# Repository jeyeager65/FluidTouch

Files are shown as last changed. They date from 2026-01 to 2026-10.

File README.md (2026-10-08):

# FluidTouch

**A touchscreen CNC controller for FluidNC-based machines**

FluidTouch provides an intuitive 800×480 touchscreen interface for controlling CNC machines running FluidNC firmware. Built on the Elecrow CrowPanel 7" ESP32-S3 HMI display with hardware-accelerated graphics and a responsive LVGL-based UI.





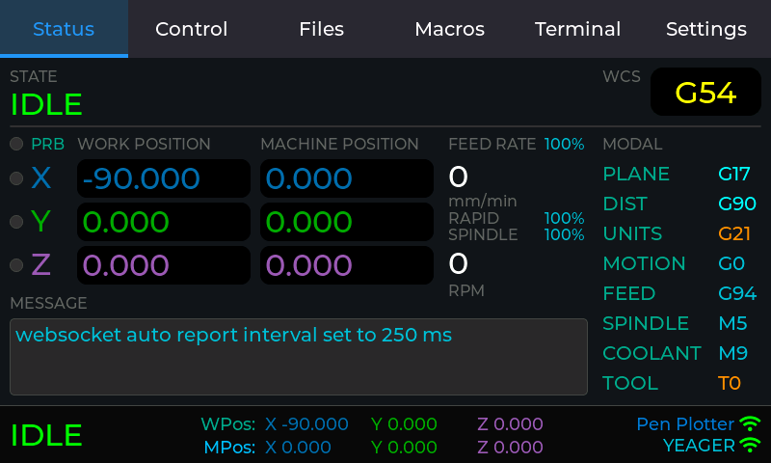
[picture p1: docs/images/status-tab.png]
FluidTouch Status


## ✨ Key Features

- **Real-time Machine Control** - Monitor position, state, feed/spindle rates with live updates from FluidNC
- **Multi-Machine Support** - Store and switch between up to 4 different CNC configurations
- **Intuitive Jogging** - Button-based and analog joystick interfaces with configurable step sizes
- **Touch Probe Operations** - Automated probing with customizable parameters for precise work coordinate setup
- **Macro Support** - Configure and store up to 9 file-based macros per machine
- **File Management** - Browse and manage files from FluidNC SD, FluidNC Flash, and Display SD card
- **Settings Backup & Restore** - Export settings to JSON, auto-import on fresh install, Clear All Settings option
- **Power Management** - Configurable display dimming, sleep, and deep sleep modes for battery operation
- **Terminal** - Execute custom commands and view FluidNC messages
- **WiFi Connectivity** - WebSocket connection to FluidNC with automatic status reporting

---

## 🚀 Quick Start

### Option 1: Web Installer (Recommended)

The easiest way to install FluidTouch is using our web-based installer:

1. **Visit:** [FluidTouch Web Installer](https://jeyeager65.github.io/FluidTouch/)
2. **Click:** "Install FluidTouch" button
3. **Connect:** Your ESP32-S3 device via USB-C
4. **Done!** Firmware flashes automatically in 30-60 seconds

**Requirements:** Chrome, Edge, or Opera browser (Web Serial API support)

### Option 2: Pre-built Binaries

Download the latest firmware from [Releases](https://github.com/jeyeager65/FluidTouch/releases) and flash using:
- [esptool.py](https://docs.espressif.com/projects/esptool/en/latest/esp32s3/index.html): `esptool.py --chip esp32s3 --port COM6 write_flash 0x10000 firmware.bin`

### Option 3: Build from Source

Refer to the **[Development Guide](./docs/development.md)** for additional instructions.

---

## 🖥️ Compatible Hardware

**Elecrow CrowPanel 7" Advance ESP32-S3 HMI Display** ⭐ *Recommended*
- ESP32-S3-WROOM-1-N16R8 (16MB Flash + 8MB PSRAM)
- 800×480 IPS RGB LCD (superior image quality)
- GT911 Capacitive Touch
- I2C Backlight Control (STC8H1K28)
- Internal battery connector (JST PH 2.0mm 2-pin)
- Optional acrylic case with battery compartment (supports ~1200mAh LiPo batteries), or a [3D printed case](./hardware/case/) with room for much larger batteries, plus a matching [table stand](./hardware/stand/)
- ⚠️ **ESP32-S3 ONLY** - ESP32-P4 versions are NOT supported
- **Hardware Versions 1.2 through 1.5 Supported**
  - **All versions:** DIP switches S0 and S1 must both be set to position 1
  - **Version 1.2:** ⚠️ Support is untested - use v1.2 firmware from web installer
  - **Versions 1.3, 1.4 and 1.5:** Fully tested and recommended. They use the same firmware: v1.4 only changed the boot/reset buttons and v1.5 only changed the silkscreen
  - **Case Note:** When using acrylic case, install 6mm M3 screws in bottom mounting inserts to prevent accidental reset button presses
- [Buy on Elecrow ↗](https://www.awin1.com/cread.php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) *(affiliate link)*

**Elecrow CrowPanel 7" Basic ESP32-S3 HMI Display**
- ESP32-S3-WROOM-1-N4R8 (4MB Flash + 8MB PSRAM)
- 800×480 TN RGB TFT LCD
- GT911 Capacitive Touch
- PWM Backlight Control
- External battery connector
- [Buy on Elecrow ↗](https://www.awin1.com/cread.php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) *(affiliate link)*

---

## 📖 Documentation

Detailed documentation is available in the [`docs/`](./docs/) folder:

- **[User Interface Guide](./docs/ui-guide.md)** - Complete UI walkthrough with screenshots
- **[Usage Instructions](./docs/usage.md)** - Operating instructions and workflows
- **[Configuration](./docs/configuration.md)** - WiFi setup, machine configuration, and settings
- **[Development Guide](./docs/development.md)** - Building, debugging, and contributing
- **[Desktop Simulator](./sim/README.md)** - Run and develop the UI on your PC, connected to a real FluidNC controller
- **[3D Printed Case](./hardware/case/README.md)** and **[Stand](./hardware/stand/README.md)** - Print files, hardware list and assembly for the Advance display

---

## 🔧 First-Time Setup

1. Power on the device
2. On the "Select Machine" screen, click the Edit button.
3. Click the "Add" button to add a new machine:
   - Name
   - Connection (currently only Wireless is supported)
   - WiFi SSID and Password (machine-specific)
   - FluidNC IP address or hostname (e.g. 192.168.0.1 or fluidnc.local)
   - WebSocket port (default: 81)
     - Port 80 is used by FluidNC v4.0+
     - Port 81 is used by WebUI v2 (FluidNC v3.x)
     - Port 82 is used by WebUI v3 (FluidNC v3.x) - only allows one connection at a time but will switch cleanly between connections
4. Click the "Save" button.
5. Click the "Done" button.
6. Click on the created machine.

---

## 🤝 Contributing

Contributions are welcome! Please read our [Development Guide](./docs/development.md) for:
- Code architecture and design patterns
- Building and testing
- Submitting pull requests

---

## 💙 Support Development

This project is provided free and open-source. Product links use affiliate codes that help offset development costs at no extra cost to you. Your support is appreciated but never required.

---

## 📝 License

This project is licensed under the MIT License - see the [LICENSE](LICENSE) file for details.

---

## 🙏 Acknowledgments

- **[FluidNC](https://github.com/bdring/FluidNC)** - CNC control firmware
- **[LVGL](https://lvgl.io/)** - Embedded graphics library
- **[LovyanGFX](https://github.com/lovyan03/LovyanGFX)** - Hardware-accelerated display driver

---

## 📧 Support

- **Issues:** [GitHub Issues](https://github.com/jeyeager65/FluidTouch/issues)

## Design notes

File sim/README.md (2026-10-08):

# FluidTouch Desktop Simulator

Runs the FluidTouch firmware UI on your PC in an 800×480 window, so you can
iterate on UI changes without flashing hardware. The simulator connects to a
**real FluidNC controller** over your PC's network, using the same code the
device uses.

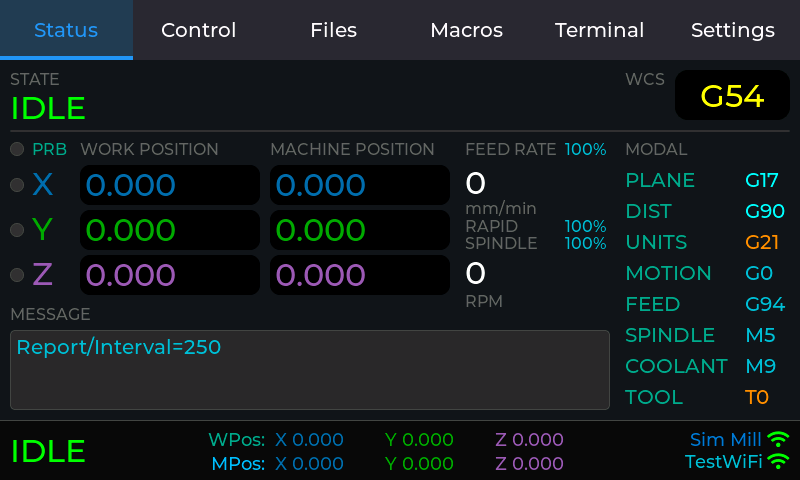
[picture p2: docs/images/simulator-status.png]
Simulator showing the Status tab


## What's real and what's simulated

| Part | In the simulator |
|---|---|
| All UI code (`src/ui/**`), `src/main.cpp`, `PowerManager` | **Real firmware code**, compiled unchanged |
| FluidNC client (`src/network/fluidnc_client.cpp`) | **Real firmware code**. Real websocket connection to your controller |
| LVGL, ArduinoJson, ArduinoWebsockets | Same versions as `platformio.ini` |
| Display | SDL window. Backlight brightness is shown as a dark overlay |
| Touchscreen | Mouse (left button = finger) |
| Board | The CrowPanel **Advance** (`HARDWARE_ADVANCE`), so UART, USB CDC and ESP-NOW connection types are available |
| UART / USB CDC links to FluidNC | Nothing is connected: they open but never receive anything |
| ESP-NOW | UDP to the fake FluidNC server (see [ESP-NOW](#esp-now)) |
| Wi-Fi | Your PC's network. Wi-Fi always reports "connected" |
| mDNS (`fluidnc.local`) | Your operating system's resolver |
| Preferences (NVS) | `sim/data/preferences.json` |
| Display SD card | The folder `sim/data/sd/` |
| File upload to controller | Real HTTP upload to the controller |
| `ESP.restart()` | Relaunches the simulator |
| Deep sleep / Power Off | Closes the simulator |
| Screenshot web server | Not included. Use F12 instead |

## One-time setup (Windows)

The simulator is built with GCC and SDL2 from [MSYS2](https://www.msys2.org/),
a package manager that provides Linux-style development tools on Windows.

1. Install MSYS2. You can use the installer from msys2.org, or:
   ```powershell
   winget install --id MSYS2.MSYS2 -e
   ```
2. Install the compiler, SDL2, CMake and Ninja:
   ```powershell
   C:\msys64\usr\bin\bash.exe -lc "pacman -Sy --noconfirm --needed mingw-w64-ucrt-x86_64-gcc mingw-w64-ucrt-x86_64-SDL2 mingw-w64-ucrt-x86_64-cmake mingw-w64-ucrt-x86_64-ninja"
   ```

If MSYS2 isn't in `C:\msys64`, set `MSYS2_ROOT` or pass `-Msys2Root <path>` to
the build script.

**Linux (untested):** install `gcc g++ cmake ninja-build libsdl2-dev`, then run
the `cmake` commands shown under [Building manually](#building-manually).

## Build and run

From the repository root, in PowerShell:

```powershell
.\sim\build.ps1 -Run      # build (incremental), then launch
.\sim\build.ps1           # build only
.\sim\build.ps1 -Clean    # delete sim/build and rebuild from scratch
```

The first build downloads LVGL, ArduinoJson and ArduinoWebsockets and takes a
few minutes. Later builds only recompile the files you changed. The
executable is `sim/build/fluidtouch_sim.exe`, and the build copies the two
DLLs it needs next to it.

### First run: add your machine

1. On the Add Machine screen, enter your controller's IP address or hostname
   (for example `192.168.1.50` or `fluidnc.local`) and its websocket port:
   80 for FluidNC v4.0+, 81 for WebUI v2, 82 for WebUI v3.
2. Wi-Fi SSID and password are required by the firmware's form validation
   but are otherwise ignored. Any non-empty values work.
3. Save, then tap the machine to connect.

Machines and settings persist in `sim/data/preferences.json`, separately
from your device.

## Using the simulator

| Input | Action |
|---|---|
| Left mouse button | Touch |
| Typing (while an on-screen keyboard is open) | Types into the field that keyboard is editing. **Enter** = ✓ (OK), **Esc** = close keyboard, **Backspace**, **←/→** move the cursor |
| **F12** | Save a screenshot to `sim/data/screenshots/` |
| Typing a line in the console window | Sends it to FluidNC. This is the same serial-monitor feature as on the device |

The console shows the firmware's normal serial log. Lines prefixed with
`[SIM]` come from the simulator itself.

### Data directory

By default everything is kept in `sim/data/` (gitignored). Use a different
folder, for example to keep separate setups, with:

```powershell
.\sim\build.ps1 -Run -- --data D:\temp\ft-test
```

| Path | Purpose |
|---|---|
| `preferences.json` | Simulated NVS. Delete it to start from a factory-fresh device |
| `sd/` | The display's SD card. Put G-code files here to test **Files → Display SD** and uploads. Put `fluidtouch_settings.json` here to test settings import. Delete or rename the folder to simulate "no SD card" |
| `screenshots/` | F12 and `--script` screenshots (BMP) |

The simulated NVS applies the same rules as the ESP32. Values are stored with
their type, and reading a key back as a different type returns the default. Keys
and namespaces longer than 15 characters are rejected. Both cases print a
`[SIM] Preferences:` warning, because the same code would fail on hardware.

### Testing without a controller: fake FluidNC server

`sim/tools/fake_fluidnc.py` is a small FluidNC stand-in that uses only the
Python standard library. It handles status reports, auto-reporting, `$G`,
jogging, homing, zeroing, overrides, hold/resume and file listing.

```powershell
python sim\tools\fake_fluidnc.py --port 81              # sample file list
python sim\tools\fake_fluidnc.py --port 81 --sd D:\gcode  # serve a real folder
```

Add a machine with URL `127.0.0.1` and the same port. Windows Firewall may
ask for permission the first time. You can drive test states from the
simulator's **Terminal** tab:

| Command | Effect |
|---|---|
| `$sim/alarm=1` | Raise `ALARM:1` (enter any alarm number) |
| `$sim/msg=Hello` | Send `[MSG:Hello]` |
| `$sim/limit=XZ` | Trigger the X and Z limit pins. `$sim/limit=` clears them |
| `$sim/probe=1` | Trigger the probe pin (`0` to clear) |
| `$sim/state=Door:0` | Report any state string, e.g. `Door:0`, `Sleep`, or an unknown one to test "DISCONNECTED" |

The fake server doesn't implement uploads (HTTP) or running jobs.

#### ESP-NOW

The fake server also plays FluidNC's side of ESP-NOW (FluidNC v4.0.4+) on UDP
port 8182. The simulator's ESP-NOW radio (`sim/src/espnow_radio_udp.cpp`)
sends each frame there as a UDP datagram that records the WiFi channel and
whether real hardware would encrypt the frame. Like FluidNC, the fake server
ignores frames on the wrong channel and rejects frames with the wrong
encryption state.

`$espnow/pair`, `$espnow/list`, `$espnow/unpair=<n>` and `$espnow/cancel` work
as they do on FluidNC. Pairings are saved to `sim/data/fake_espnow_pairings.json`.

| Option | Effect |
|---|---|
| `--espnow-pair` | Open the 60 second pairing window at startup |
| `--espnow-channel 11` | Put FluidNC on another WiFi channel (default 6) |
| `--espnow-port 0` | Turn ESP-NOW off |

Set `FT_ESPNOW_SERVER=host:port` if the fake server isn't on `127.0.0.1:8182`.

`espnow_link_test` checks the ESP-NOW link without the UI. It pairs, sends
`$G` and `?`, and passes once the reply, an `ok` and a status report arrive:

```powershell
python sim\tools\fake_fluidnc.py --espnow-pair
sim\build\espnow_link_test.exe --pair    # pair and save the pairing
sim\build\espnow_link_test.exe           # reconnect with the saved pairing
```

`--hold --seconds 40` keeps it running, so you can restart the fake server
(optionally on another `--espnow-channel`) and check that it reconnects.

### Scripted input and automated screenshots

`--script` plays back touch and keyboard input. It's useful for regenerating
documentation screenshots or quickly checking that a screen still renders. You
can pass the commands inline or as a file path:

```powershell
sim\build\fluidtouch_sim.exe --script "wait 4000; click 215 170; wait 5000; shot status.bmp; exit"
```

| Command | Meaning |
|---|---|
| `wait <ms>` | Pause |
| `click <x> <y>` | Tap (100 ms press) |
| `press <x> <y>` / `release` | Finger down / up (for press-and-hold or drags) |
| `type <text>` | Type into the field the on-screen keyboard is editing |
| `key <enter\|esc\|backspace\|left\|right>` | Special keys |
| `shot [file.bmp]` | Screenshot. Relative names go to `<data>/screenshots/` |
| `exit` | Quit |

Coordinates are screen pixels (0–799, 0–479). Add a short `wait` after actions
that animate, such as tab switches or the keyboard closing and the dialog
scrolling back, or the next click may land on the wrong spot. `#` starts a
comment in script files. Restarts drop the script so it isn't replayed.

## Limitations: still check these on hardware

- **Performance.** A PC is far faster than the ESP32-S3 and doesn't use PSRAM
  timing. Slow redraws or large lists won't show up here. The LVGL memory
  pool *is* the same size (1 MB, from `lv_conf.h`), so running out of LVGL
  memory will reproduce.
- **Touch feel.** Mouse precision and the GT911 touchscreen feel different,
  so check small targets and drag gestures on the device.
- **Display.** Colors and viewing angles differ, especially on the Basic's TN panel.
  Display rotation (180°) is saved but not applied to the window.
- **Wi-Fi.** It's always "connected", so the Wi-Fi-failure dialogs can't be
  triggered. Controller disconnects can be tested by stopping the
  controller or the fake server.
- **Blocking behaviour.** `delay()` keeps the window responsive, but the
  firmware's blocking waits (for example the connect retries) take real time,
  just like on the device.
- **Heap and PSRAM numbers** printed in the log are fixed placeholder values.
- The screenshot web server and the hardware-specific parts of the display,
  touch and backlight drivers aren't compiled.

## How it works

The simulator is a separate CMake project in `sim/` that compiles the
firmware's own sources together with a thin desktop platform layer:

```
sim/
├── CMakeLists.txt        builds lvgl + ArduinoWebsockets + src/** + sim/src/**
├── build.ps1             Windows build/run helper (uses MSYS2 UCRT64)
├── include/              desktop versions of Arduino/ESP32 headers (searched BEFORE include/)
│   ├── Arduino.h, WString.h, Print.h, IPAddress.h   Arduino core subset
│   ├── Preferences.h, FS.h, SD.h, SPI.h, Wire.h     storage / buses
│   ├── WiFi.h, WiFiClient.h, ESPmDNS.h, HTTPClient.h networking
│   ├── esp_heap_caps.h, esp_sleep.h                 ESP-IDF bits
│   ├── core/display_driver.h                        SDL version of the display driver API
│   ├── lv_conf.h                                    wraps ../../include/lv_conf.h, turns on SDL
│   └── sim_ws_platform.h                            desktop TCP client for ArduinoWebsockets
├── src/                  implementations of the above + sim_main.cpp (main(), scripts, F12)
└── tools/fake_fluidnc.py
```

Key points:

- **Firmware sources are compiled unchanged.** Every `src/**/*.cpp` is
  included except the three hardware-only files `src/core/display_driver.cpp`,
  `src/core/touch_driver.cpp` and `src/network/screenshot_server.cpp`, which
  have replacements in `sim/src/`. `sim_main.cpp` provides `main()` and calls
  the firmware's `setup()` once and then `loop()` forever, just like the Arduino core.
- **Header shadowing.** `sim/include` comes before `include/` on the include
  path, so `#include <Arduino.h>`, `<Preferences.h>`, `"core/display_driver.h"`
  and the others resolve to the desktop versions.
- **Websockets.** ArduinoWebsockets only selects a TCP backend for ESP and
  Teensy boards, so `sim_ws_platform.h` is force-included (`gcc -include`)
  into every C++ file and supplies `WSDefaultTcpClient`, backed by
  Winsock/BSD sockets in `sim/src/net.cpp`.
- **`-funsigned-char`** matches the ESP32 (Xtensa) compiler, where `char` is
  unsigned. The firmware relies on this, for example for FluidNC's realtime
  command bytes.

## Maintaining the simulator

- **The firmware starts using a new Arduino/ESP32 API.** The simulator build
  will fail with an undeclared identifier. Add the missing function to the
  matching header in `sim/include/`, implemented in `sim/src/` if it needs
  real behaviour. Keep each addition small: a no-op is fine for hardware-only
  calls.
- **A new hardware-only source file** (a new driver, for example) needs a
  desktop replacement in `sim/src/`, or it must be excluded with a
  `list(FILTER ...)` line in `sim/CMakeLists.txt`.
- **Library upgrades.** When bumping LVGL, ArduinoJson or ArduinoWebsockets in
  `platformio.ini`, update the matching `GIT_TAG` in `sim/CMakeLists.txt`, then
  rebuild with `-Clean`.
- **`lv_conf.h` changes** apply to both builds automatically. Only SDL settings
  live in `sim/include/lv_conf.h`.

### Building manually

```bash
# from an MSYS2 UCRT64 shell, or with C:\msys64\ucrt64\bin first on PATH
cmake -S sim -B sim/build -G Ninja -DCMAKE_BUILD_TYPE=Debug
cmake --build sim/build
sim/build/fluidtouch_sim --help
```

`sim/build/compile_commands.json` is generated for clangd/IntelliSense.

## Troubleshooting

| Problem | Fix |
|---|---|
| `MSYS2 UCRT64 gcc not found` | Install MSYS2 and the packages above, or point `-Msys2Root` at your install |
| Exe exits immediately with code 127, or "DLL not found" | Run from `sim/build/`, where the build copies `SDL2.dll` and `libwinpthread-1.dll`. Rebuild if they're missing |
| CMake picks up a different gcc (Cygwin, Strawberry Perl, …) | Use `build.ps1`, which puts MSYS2 first on `PATH`, or run `.\sim\build.ps1 -Clean` |
| `fluidnc.local` doesn't resolve | Check `ping fluidnc.local` from the same PC. If that fails too, use the IP address |
| "Connection failed" | Check the port (80/81/82 depends on the FluidNC version) and that the PC can reach the controller |
| UI looks stale after pulling changes | `.\sim\build.ps1 -Clean` |

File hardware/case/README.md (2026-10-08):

# Elecrow CrowPanel Advance 7" Case

A two-piece 3D printed case for the 7" CrowPanel **Advance** (it does not fit the Basic). It has a front bezel (Top) and a back shell (Bottom) that screw together at the corners. Inside there is room for a battery up to 12 mm thick, switched by a rocker switch on the side. The case has openings for the SD card, USB-C and the switch, a light pipe for the charge/power LEDs, and printed boot/reset buttons.

It was designed for FluidTouch but doesn't depend on it, so it works for any project using this display. There is also a matching [table stand](../stand/).

> **Connections:** the case works with wireless or USB connections. It has no opening for a UART cable, so it doesn't support a wired UART connection.

## Files

`CrowPanelAdvance7Case.FCStd` is the FreeCAD source model (FreeCAD 1.1). Every part is also exported as both `.3mf` and `.stl`, already in its print orientation:

| Part | Files |
|---|---|
| Front bezel | `CrowPanelAdvance7Case-Top.3mf` / `.stl` |
| Back shell | `CrowPanelAdvance7Case-Bottom.3mf` / `.stl` |
| Battery bracket | `CrowPanelAdvance7Case-BatteryBracket.3mf` / `.stl` |
| Boot/reset button, v1.4 and v1.5 boards | `CrowPanelAdvance7Case-Button-v1.4.3mf` / `.stl` |
| Boot/reset button, v1.3 boards | `CrowPanelAdvance7Case-Button-v1.3.3mf` / `.stl` |

## Printing

Printed on a Bambu Lab P1S in PLA: 0.4 mm nozzle, 0.20 mm layers, 3 walls, 30% infill. Nothing needs supports.

| Part | Qty | Orientation | Notes |
|---|---|---|---|
| Bottom | 1 | Flat side down | The screw counterbores are bridged by a single layer. Poke through it when assembling. |
| Top | 1 | Top side down | |
| Button | 2 | Top of the button down | Use the button for your board revision. Needs a brim (a 0.5 mm brim-object gap helps it come off cleanly). May need cleanup with a razor. |
| Battery Bracket | 2 | On its side | |

The v1.3 and v1.4 boards differ only in their boot/reset buttons, and v1.5 only changed the silkscreen, so the Top, Bottom and brackets are the same for all of them. v1.5 boards use the v1.4 buttons. The button fit is tight, so you may need to adjust it for your printer.

## Hardware

Screws (button or socket head):
- 4 × M3 × 20 mm to join the Top and Bottom
- 4 × M3 × 6 mm to attach the battery brackets

Battery and switch wiring:
- 1 × [15 × 10 mm rocker switch](https://www.amazon.com/dp/B0CSJTHZHR)
- 2 × [0.187" spade terminals](https://www.amazon.com/dp/B01N5APVEE) to connect to the switch, or solder the wires to it instead
- [JST PH2.0 male and female connectors](https://www.amazon.com/dp/B088NFRNZ2), or cut the battery leads and splice them
- 22 AWG wire and heat shrink tubing
- A LiPo battery up to 12 mm thick. Tested with an [8000 mAh 126090](https://www.amazon.com/dp/B0C2HN5M7M) (12 × 60 × 90 mm) and a [10000 mAh](https://www.amazon.com/dp/B093WS6C66). At least 4000 mAh is recommended.

> **Check the battery polarity.** Every battery and wire color tested so far has been reversed compared with the display's battery plug. Match the polarity printed on the display PCB, swapping the pins in the connector if needed.

## Assembly

The buttons are not attached. They sit loose in the button holes in the Bottom and are held in place between the case and the display board.

- **v1.3 board:** assemble in either order.
- **v1.4 and v1.5 boards:** the board's switches are much shorter, so place the printed buttons in the holes in the Bottom first, then fit the Top and display on top.

The v1.3 buttons are sized for that board's original 4.5 × 4.5 mm, 9 mm tall tactile switches. If you replace a switch on a v1.3 board with a shorter one, the buttons won't reach it.

## Editing the model

The model tree has one group, **Printed Parts**: Top, Bottom, both button versions and the battery bracket. The v1.4 buttons are shown by default. Each button version has a linked copy in the second hole, and the bracket has a linked copy on the second pair of posts. Each copy is the same part, moved into place.

Features are named for what they do (e.g. `TopUSBCCutout`, `BottomPowerSwitchCutout`, `LightPipePost`, `BatteryStop`). Each port opening is split between the Top and Bottom bodies.

The CrowPanel board itself is not included, to keep the file small. To check fit, import Elecrow's [STEP model of the CrowPanel Advance 7"](https://github.com/Elecrow-RD/CrowPanel-Advance-7-HMI-ESP32-S3-AI-Powered-IPS-Touch-Screen-800x480/tree/master/3D%20file) into the document.

The file is saved uncompressed so git can store changes to it efficiently. To keep it that way, set **Edit → Preferences → General → Document → Compression level** to 0 before saving.

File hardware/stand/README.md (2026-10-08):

# Elecrow CrowPanel Advance 7" Stand

A table-edge stand for the [CrowPanel Advance 7" case](../case/). The case drops into the cradle, which holds it angled back. The stand can be screwed to the top of a table or to the front face of one.

## Files

| File | What it is |
|---|---|
| `CrowPanelAdvance7Stand.FCStd` | FreeCAD source model (FreeCAD 1.1) |
| `CrowPanelAdvance7Stand.3mf` / `.stl` | The stand, already in print orientation |

## Printing

Print 1, base down, with no supports. It was printed on a Bambu Lab P1S in PLA: 0.4 mm nozzle, 0.20 mm layers, 3 walls, 25% infill.

## Mounting

There are two pairs of counterbored screw holes. They are 4 mm holes with 12 mm counterbores, sized to take whatever screws suit your table, such as #6–#8 wood screws or M3–M4 screws.

- **Base holes:** for screwing the stand to the top of a table.
- **Back holes:** for screwing it to the front face of a table. You will probably need a spacer block behind it so the stand sits far enough out from the table.

Front side holders make the case harder to knock off the stand.

The case can sit in the stand either way round. Side holes at both ends let you reach the power switch, and a channel inside each end keeps the switch from being flipped as you drop the case in.

## Editing the model

The model is a single body. One half is modelled and mirrored (`MirrorHalf`), so changes to one end apply to both. Features are named for what they do (e.g. `FrontHolder`, `SwitchChannel`, `BackScrewHole`, `BaseScrewCounterbore`).

The file is saved uncompressed so git can store changes to it efficiently. To keep it that way, set **Edit → Preferences → General → Document → Compression level** to 0 before saving.

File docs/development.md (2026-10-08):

# FluidTouch Development Guide

> Building, debugging, and contributing to FluidTouch

## Table of Contents

- [Development Environment](#development-environment)
- [Building from Source](#building-from-source)
- [Desktop Simulator](#desktop-simulator)
- [Project Architecture](#project-architecture)
- [Code Style Guidelines](#code-style-guidelines)
- [Debugging](#debugging)
- [Contributing](#contributing)

---

## Development Environment

### Prerequisites

**Required:**
- [Visual Studio Code](https://code.visualstudio.com/)
- [PlatformIO IDE Extension](https://platformio.org/install/ide?install=vscode)
- [Git](https://git-scm.com/)
- USB-C cable with data support

**Optional:**
- Elecrow CrowPanel 7" ESP32-S3 HMI Display:
  - [Basic version](https://www.awin1.com/cread.php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) (4MB flash) *(affiliate link)*
    - 800×480 TN RGB TFT LCD
    - PWM backlight control
    - External battery connector
  - [Advance version](https://www.awin1.com/cread.php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) (16MB flash) *(affiliate link)*
    - 800×480 IPS RGB LCD (superior image quality vs Basic)
    - I2C backlight control
    - Internal battery connector with JST PH 2.0mm 2-pin connector
    - Optional acrylic case includes space for battery (e.g., 1200mAh lithium polymer battery)
    - ⚠️ **ESP32-S3 ONLY** - ESP32-P4 versions are NOT supported
    - ⚠️ **Advance Version Compatibility:** Supports hardware Versions 1.2 through 1.5
    - **DIP Switch Configuration:** All versions require DIP switches S0 and S1 set to position 1
    - **Versions 1.3, 1.4 and 1.5:** Fully tested (use `elecrow-crowpanel-7-advance-v13` build environment for all three; v1.4 only changed the boot/reset buttons and v1.5 only changed the silkscreen)
    - **Version 1.2:** ⚠️ Untested (use `elecrow-crowpanel-7-advance-v12` build environment)
- Serial terminal (PlatformIO includes one)
- Chrome/Edge browser (for ESP Web Tools testing)

### Hardware Notes

**Advance Display with Acrylic Case:**
- Boot and reset buttons are accessible through holes in the acrylic case
- ⚠️ **Important:** If placed on a flat surface, the device may press the reset button and restart
- **Solution:** Install 6mm M3 screws in the mounting inserts on the bottom to create clearance

### Repository Setup

```bash
# Clone repository
git clone https://github.com/jeyeager65/FluidTouch.git
cd FluidTouch

# Checkout development branch
git checkout dev

# Open in VS Code
code .
```

---

## Building from Source

### PlatformIO Commands

**Build Environments:**
- `elecrow-crowpanel-7-basic` - Basic hardware (4MB flash, PWM backlight)
- `elecrow-crowpanel-7-advance-v12` - Advance v1.2 hardware (16MB flash, I2C backlight)
- `elecrow-crowpanel-7-advance-v13` - Advance v1.3 hardware (16MB flash, I2C backlight)

**Windows PowerShell:**
```powershell
# Build only (Basic)
& "$env:USERPROFILE\.platformio\penv\Scripts\platformio.exe" run -e elecrow-crowpanel-7-basic

# Build only (Advance v1.2)
& "$env:USERPROFILE\.platformio\penv\Scripts\platformio.exe" run -e elecrow-crowpanel-7-advance-v12

# Build only (Advance v1.3)
& "$env:USERPROFILE\.platformio\penv\Scripts\platformio.exe" run -e elecrow-crowpanel-7-advance-v13

# Build and upload (Basic)
& "$env:USERPROFILE\.platformio\penv\Scripts\platformio.exe" run --target upload -e elecrow-crowpanel-7-basic

# Build and upload (Advance v1.2)
& "$env:USERPROFILE\.platformio\penv\Scripts\platformio.exe" run --target upload -e elecrow-crowpanel-7-advance-v12

# Build and upload (Advance v1.3)
& "$env:USERPROFILE\.platformio\penv\Scripts\platformio.exe" run --target upload -e elecrow-crowpanel-7-advance-v13

# Clean build
& "$env:USERPROFILE\.platformio\penv\Scripts\platformio.exe" run -t clean

# Serial monitor
& "$env:USERPROFILE\.platformio\penv\Scripts\platformio.exe" device monitor -b 115200
```

**Linux/macOS:**
```bash
# Build only (Basic)
platformio run -e elecrow-crowpanel-7-basic

# Build only (Advance v1.2)
platformio run -e elecrow-crowpanel-7-advance-v12

# Build only (Advance v1.3)
platformio run -e elecrow-crowpanel-7-advance-v13

# Build and upload (Basic)
platformio run --target upload -e elecrow-crowpanel-7-basic

# Build and upload (Advance v1.2)
platformio run --target upload -e elecrow-crowpanel-7-advance-v12

# Build and upload (Advance v1.3)
platformio run --target upload -e elecrow-crowpanel-7-advance-v13

# Clean build
platformio run -t clean

# Serial monitor
platformio device monitor -b 115200
```

### Build Output

**Flash Usage:** 
- Basic: ~57% (1.86MB of 3.25MB)
- Advance v1.2: ~28% (1.86MB of 6.5MB)
- Advance v1.3: ~28% (1.86MB of 6.5MB)

**RAM Usage:** ~1.0% (82KB of 8.5MB)

**Binary Locations:**
- Basic Firmware: `.pio/build/elecrow-crowpanel-7-basic/firmware.bin`
- Advance v1.2 Firmware: `.pio/build/elecrow-crowpanel-7-advance-v12/firmware.bin`
- Advance v1.3 Firmware: `.pio/build/elecrow-crowpanel-7-advance-v13/firmware.bin`

---

## Desktop Simulator

The `sim/` folder builds the firmware UI as a Windows desktop app (SDL2
window, mouse = touch) that connects to a **real FluidNC controller** over
your PC's network. The UI code, `main.cpp` and the FluidNC client are
compiled unchanged, so most UI work can be done without flashing hardware.

```powershell
.\sim\build.ps1 -Run
```

One-time setup (MSYS2 + GCC + SDL2), usage, the fake FluidNC server for
offline testing, scripted screenshots and how the simulator works are all in
**[sim/README.md](../sim/README.md)**.

Still check performance, touch feel and display colors on the device before
releasing. See the simulator's limitations list.

---

## Project Architecture

### Directory Structure

```
FluidTouch/
├── include/                 # Header files
│   ├── config.h            # Configuration constants
│   ├── core/               # Hardware drivers
│   ├── network/            # Network modules
│   └── ui/                 # UI headers
│       ├── ui_theme.h      # Centralized colors/constants
│       └── tabs/           # Tab UI headers
├── src/                    # Implementation files
│   ├── main.cpp           # Entry point
│   ├── core/              # Driver implementations
│   ├── network/           # Network implementations
│   └── ui/                # UI implementations
├── web/                    # ESP Web Tools installer
├── docs/                   # Documentation
└── platformio.ini         # Build configuration
```

### Module Organization

See `.github/copilot-instructions.md` for detailed architecture documentation.

**Key Principles:**
1. **Hardware Platform** - ESP32-S3 with 4MB flash + 8MB PSRAM
2. **Driver Modules** - DisplayDriver, TouchDriver (in `core/`)
3. **Network Modules** - ScreenshotServer, FluidNCClient (in `network/`)
4. **UI Hierarchy** - Modular tab system with static factory methods

---

## Code Style Guidelines

### Naming Conventions

**Classes:**
```cpp
class UITabControl {          // PascalCase
    static void create();      // camelCase methods
private:
    static lv_obj_t *button;   // snake_case for LVGL objects
};
```

**Files:**
- Headers: `ui_tab_control.h` (snake_case)
- Implementation: `ui_tab_control.cpp`
- Match class name pattern

**Constants:**
```cpp
// config.h
#define SCREEN_WIDTH 800

// ui_theme.h
namespace UITheme {
    static constexpr lv_color_t ACCENT_PRIMARY = ...;
}
```

### Memory Management

**Critical Rules:**
1. **Large buffers (>10KB):** Use `heap_caps_malloc(..., MALLOC_CAP_SPIRAM)`
2. **LVGL objects:** Use LVGL's allocator (automatic PSRAM via `lv_conf.h`)
3. **Delta checking:** Only update UI when values change
4. **Static pointers:** Required for UI elements needing live updates

### UI Development

**Theme Colors:**
```cpp
// NEVER use lv_color_hex() directly
lv_obj_set_style_bg_color(obj, UITheme::BG_MEDIUM, 0);  // ✅ Good
lv_obj_set_style_text_color(obj, lv_color_hex(0x00FF00), 0);  // ❌ Bad
```

**Event Handling:**
```cpp
// Use LV_EVENT_CLICKED for touch interactions
lv_obj_add_event_cb(btn, event_handler, LV_EVENT_CLICKED, nullptr);
```

**Label Updates:**
```cpp
// Delta checking to prevent unnecessary redraws
static float last_value = -9999.0f;
if (current_value != last_value) {
    lv_label_set_text_fmt(label, "%.3f", current_value);
    last_value = current_value;
}
```

### Module Structure

**Header Pattern:**
```cpp
#ifndef UI_TAB_EXAMPLE_H
#define UI_TAB_EXAMPLE_H

#include <lvgl.h>

class UITabExample {
public:
    static void create(lv_obj_t *parent);
    static void update();  // Optional, for dynamic updates
    
private:
    static lv_obj_t *label;
    static void event_handler(lv_event_t *e);
};

#endif
```

**Implementation Pattern:**
```cpp
#include "ui/tabs/ui_tab_example.h"
#include "ui/ui_theme.h"

// Static member initialization
lv_obj_t *UITabExample::label = nullptr;

void UITabExample::create(lv_obj_t *parent) {
    // Clear scrolling if fixed layout
    lv_obj_clear_flag(parent, LV_OBJ_FLAG_SCROLLABLE);
    
    // Create UI elements
    label = lv_label_create(parent);
    lv_label_set_text(label, "Example");
    lv_obj_set_style_text_color(label, UITheme::TEXT_LIGHT, 0);
}
```

---

## Debugging

### Serial Debugging

**Monitor Output:**
```bash
platformio device monitor -b 115200
```

**Debug Macros:**
```cpp
Serial.println("Debug message");
Serial.printf("Value: %d\n", value);
Serial.printf("Free heap: %d, Free PSRAM: %d\n", 
    ESP.getFreeHeap(), ESP.getFreePsram());
```

### Screenshot Server

Access live display at `http://[ESP32-IP]`

**Benefits:**
- No serial connection needed
- See actual rendered UI
- Document UI states
- Debug layout issues
- Share visual bugs

### Memory Monitoring

**Check Heap:**
```cpp
Serial.printf("Free heap: %d bytes\n", ESP.getFreeHeap());
Serial.printf("Free PSRAM: %d bytes\n", ESP.getFreePsram());
Serial.printf("Min free heap: %d bytes\n", ESP.getMinFreeHeap());
```

**LVGL Memory:**
```cpp
lv_mem_monitor_t mon;
lv_mem_monitor(&mon);
Serial.printf("LVGL used: %d KB\n", mon.total_size - mon.free_size);
```

### Common Issues

**Out of Memory:**
- Check large buffers use PSRAM (`heap_caps_malloc`)
- Monitor LVGL heap usage
- Verify display buffers allocated correctly

**UI Not Updating:**
- Ensure `lv_tick_inc()` and `lv_timer_handler()` called in main loop
- Check static pointers initialized
- Verify event callbacks registered

**Touch Not Working:**
- Check serial log for GT911 initialization
- Verify I2C pins (SDA=19, SCL=20, RST=38)
- Test with screenshot server

---

## Contributing

### Development Workflow

1. **Fork** the repository
2. **Create branch** from `dev`:
   ```bash
   git checkout dev
   git pull origin dev
   git checkout -b feature/my-feature
   ```
3. **Make changes** following code style guidelines
4. **Test thoroughly** on hardware
5. **Commit** with clear messages:
   ```bash
   git commit -m "Add feature: description"
   ```
6. **Push** to your fork:
   ```bash
   git push origin feature/my-feature
   ```
7. **Create Pull Request** to `dev` branch

### Pull Request Guidelines

**Include:**
- Clear description of changes
- Screenshots/videos for UI changes
- Test results on hardware
- Any breaking changes noted
- Updated documentation if needed

**Requirements:**
- Code follows style guidelines
- No compiler warnings
- Flash usage remains reasonable (<70%)
- Tested on actual hardware preferred

### Branching Strategy

- **`main`:** Stable releases only
- **`dev`:** Active development
- **Feature branches:** `feature/description`
- **Bug fixes:** `fix/description`

### Testing Checklist

- [ ] Compiles without warnings
- [ ] Simulator still builds (`.\sim\build.ps1`)
- [ ] Flash usage acceptable
- [ ] UI responsive on hardware
- [ ] Touch input works correctly
- [ ] FluidNC communication stable
- [ ] WiFi connects reliably
- [ ] No memory leaks
- [ ] Screenshot server accessible
- [ ] State transitions handled
- [ ] Error conditions tested

---

## Resources

**FluidTouch:**
- [GitHub Repository](https://github.com/jeyeager65/FluidTouch)
- [Issues](https://github.com/jeyeager65/FluidTouch/issues)

**Dependencies:**
- [LVGL Documentation](https://docs.lvgl.io/)
- [LovyanGFX](https://github.com/lovyan03/LovyanGFX)
- [FluidNC](https://github.com/bdring/FluidNC)
- [ESP32-S3 Technical Reference](https://www.espressif.com/sites/default/files/documentation/esp32-s3_technical_reference_manual_en.pdf)

**Hardware:**
- [Elecrow CrowPanel 7" Basic](https://www.awin1.com/cread.php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) *(affiliate link)*
- [Elecrow CrowPanel 7" Advance](https://www.awin1.com/cread.php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) *(affiliate link)*
- [ESP32-S3 Datasheet](https://www.espressif.com/sites/default/files/documentation/esp32-s3_datasheet_en.pdf)

---

*For architecture details, see `.github/copilot-instructions.md`*

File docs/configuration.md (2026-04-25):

# FluidTouch Configuration Guide

> Detailed configuration options and settings

## Table of Contents

- [WiFi Configuration](#wifi-configuration)
- [Machine Configuration](#machine-configuration)
- [Jog Settings](#jog-settings)
- [Probe Settings](#probe-settings)
- [Preferences Storage](#preferences-storage)

---

## Machine Configuration

### Adding a Machine

**Machine Selection Screen → Edit → Add Machine**

1. **Name:** Descriptive name (e.g., "CNC Router", "Pen Plotter")
   - Up to 32 characters
   - Used for identification in status bar

2. **Connection** Connection Type - currently only Wireless is implemented.

3. **WiFi SSID** Wireless Network SSID.
   -- SSIDs are case sensitive.

4. **Password** WiFi Password

5. **FluidNC URL:** FluidNC network address
   - IP address format: `192.168.1.100`
   - Hostname format: `fluidnc.local` (mDNS)

6. **Port:** WebSocket port number
   - Default: `81`
   - Port 80 is used by FluidNC v4.0+
   - Port 81 is used by WebUI v2 (FluidNC v3.x)
   - Port 82 is used by WebUI v3 (FluidNC v3.x) - only allows one connection at a time but will switch cleanly between connections

### Editing a Machine

**Machine Selection Screen → Edit**

1. Select machine in list
2. Tap **Edit** button
3. Modify any settings
4. Tap **Save**
5. Click **Done** to return to Machine Selection Screen

### Deleting a Machine

1. Select machine in list
2. Tap **Delete** button
3. Confirm deletion
4. Machine removed from storage

### Reordering Machines

Use **Up/Down** buttons to:
- Move frequently used machines to top
- Organize by usage or location
- Group similar machines together

### Machine Storage

- Maximum: 4 machines
- Stored in ESP32 NVS (non-volatile storage)
- Survives power cycles and firmware updates
- Macros are configurable after connection

---

## Jog Settings

**Settings → Jog**

Configure default jogging behavior:

### XY Max Feed Rate

- **Range:** 1-10000 mm/min
- **Default:** 3000 mm/min
- **Usage:**
  - Maximum speed for XY jogging
  - Used by joystick (0-100% scaling)
  - Used by jog buttons with selected step size
  
### Z Max Feed Rate

- **Range:** 1-5000 mm/min
- **Default:** 1000 mm/min
- **Usage:**
  - Maximum speed for Z-axis jogging
  - Used by joystick (0-100% scaling)
  - Used by Z jog buttons

### A Max Feed Rate

- **Range:** 1-10000 mm/min (or deg/min)
- **Default:** 1000 mm/min
- **Usage:**
  - Maximum speed for A-axis jogging
  - Used by joystick Z/A slider in A mode
  - Used by A jog buttons
- **Note:** Only visible when A-axis is enabled for the selected machine (Settings → General)

### XY Steps

- **Format:** Comma-separated values (e.g., `100,50,10,1,0.1`)
- **Default:** `100,50,10,1,0.1`
- **Usage:** Defines the step size buttons shown in the XY jog section

### Z Steps

- **Format:** Comma-separated values (e.g., `50,25,10,1,0.1`)
- **Default:** `50,25,10,1,0.1`
- **Usage:** Defines the step size buttons shown in the Z jog section

### A Steps

- **Format:** Comma-separated values (e.g., `50,25,10,1,0.1`)
- **Default:** `50,25,10,1,0.1`
- **Usage:** Defines the step size buttons shown in the A jog section
- **Note:** Only visible when A-axis is enabled for the selected machine (Settings → General)

---

## Probe Settings

**Settings → Probe**

Default values for touch probe operations:

### Feed Rate

- **Range:** 1-1000 mm/min
- **Default:** 100 mm/min
- **Usage:** Probing speed toward target

### Max Distance

- **Range:** 1-500 mm
- **Default:** 50 mm
- **Usage:** Maximum travel distance while probing

### Retract Distance

- **Range:** 0-50 mm
- **Default:** 2 mm
- **Usage:** Pull-off distance after probe contact

### Probe Thickness

- **Range:** 0-50 mm
- **Default:** 0 mm
- **Usage:** Thickness of probe plate/puck
  
**Usage:**
- Enter actual probe plate thickness
- FluidTouch compensates automatically
- Zero value for direct surface probing

---

## Power Settings

**Settings → Power**

Configure power management and display brightness:

### Power Management

- **Enable/Disable:** Toggle power saving features
- **Dim Timeout:** Time until screen dims (Disabled, 15s, 30s, 45s, 60s, 90s, 120s, 300s)
- **Sleep Timeout:** Time until screen turns off (Disabled, 60s, 120s, 300s, 600s, 900s, 1800s, 3600s)
- **Deep Sleep:** Time until deep sleep mode (Disabled, 5min, 10min, 15min, 30min, 60min, 90min)

### Brightness Control

- **Normal Brightness:** Active display brightness (25%, 50%, 75%, 100%)
- **Dim Brightness:** Dimmed display brightness (5%, 10%, 25%, 50%)

**Notes:**
- Power saving only applies in IDLE and DISCONNECTED states
- During RUN, ALARM, HOLD, or JOG states, display stays at full brightness
- Touch activity resets timers and restores full brightness
- Deep sleep mode requires reset button to wake

---

## Backup & Restore

### Exporting Settings

**Settings → Backup → Export Settings**

Creates a backup file on the Display SD card:

**Export File:**
- Location: `/fluidtouch_settings.json` (root of Display SD card)
- Format: JSON (human-readable, editable)
- Version: 1.0

**Exported Data:**
- Machine configurations (name, connection type, hostname/IP, port, SSID)
- Jog settings (XY feed rate, Z feed rate)
- Probe settings (feed rate, max distance, retract distance, thickness)
- Macros (up to 9 per machine)
- Power management settings (enabled, timeouts, brightness levels, deep sleep)
- UI preferences (folders on top)

**Security:**
- WiFi passwords are NOT included in the export
- Empty password fields are exported instead
- You must manually re-enter WiFi passwords after importing

### Importing Settings

**Automatic Import:**
1. Copy `fluidtouch_settings.json` to Display SD card root
2. Clear all settings (or start with fresh install)
3. Restart device
4. If no machines are configured, settings are automatically imported
5. Device restarts again after successful import

**Manual Import:**
1. Go to **Settings → General**
2. Tap **Clear All Settings**
3. Confirm warning dialog
4. Device restarts and auto-imports if settings file exists
5. Configure WiFi passwords for each machine

### Clearing All Settings

**Settings → General → Clear All Settings**

Permanently deletes all stored data:
- All machine configurations
- All macros
- Power management settings
- UI preferences
- System settings

**Process:**
1. Confirmation dialog warns of permanent deletion
2. Lists all data that will be removed
3. Suggests exporting settings first
4. Two buttons: "Clear & Restart" (left), "Cancel" (right)
5. Clearing triggers immediate device restart
6. Returns to initial setup state

⚠️ **Warning:** This action cannot be undone! Consider exporting settings before clearing.

---

## Preferences Storage

FluidTouch uses ESP32 NVS (Non-Volatile Storage) for persistent data:

### Stored Data

**Machine Configurations:**
- Up to 4 machine profiles
- Name, hostname/IP, port, WiFi SSID/password
- Selected machine index

**Jog Settings:**
- XY max feed rate
- Z max feed rate

**Probe Settings:**
- Feed rate
- Max distance
- Retract distance
- Probe thickness

**Power Settings:**
- Power management enabled/disabled
- Dim timeout, sleep timeout, deep sleep timeout
- Normal brightness (0-100%)
- Dim brightness (0-100%)

**Macros:**
- Up to 9 macros per machine
- Macro names and G-code content

**File Browser:**
- Folders on top setting

### Backup Options

**Export Settings (Recommended):**
- Creates JSON backup file on Display SD card
- See [Backup & Restore](#backup--restore) section above

### Clearing Preferences

**Option 1 - Clear All Settings (Settings Tab):**
1. Go to **Settings → General**
2. Tap **Clear All Settings**
3. Confirm deletion
4. Device restarts with factory defaults

**Option 2 - Flash Erase:**
1. Flash new firmware with "Erase Flash" option
2. Or send erase command via esptool:
   ```bash
   esptool.py --chip esp32s3 erase_flash
   ```
3. Then re-flash firmware

⚠️ **Warning:** This erases all stored configurations!

---

*For usage instructions, see [Usage Guide](./usage.md)*

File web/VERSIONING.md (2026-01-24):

# FluidTouch Web Installer - Version Management

## Overview

The FluidTouch web installer supports multiple firmware versions with dropdown selection. This allows users to choose between stable releases, preview builds, and different hardware variants.

## Directory Structure

```
web/
├── firmware/
│   ├── {version}/              # Stable release versions
│   │   ├── basic/
│   │   │   ├── firmware.bin
│   │   │   ├── bootloader.bin
│   │   │   ├── partitions.bin
│   │   │   └── boot_app0.bin
│   │   └── advance/
│   │       ├── firmware.bin
│   │       ├── bootloader.bin
│   │       ├── partitions.bin
│   │       └── boot_app0.bin
│   └── preview/
│       └── {version_branchname}/   # Preview builds from feature branches
│           ├── basic/
│           └── advance/
├── versions.json               # Version registry
├── manifest_basic.json         # Legacy manifest (for local/basic builds)
└── manifest_advance.json       # Legacy manifest (for local/advance builds)
```

## versions.json Structure

```json
{
  "default_version": "1.0.2",
  "default_hardware": "advance-v1.3",
  "versions": [
    {
      "id": "1.0.2",
      "hardware": ["basic", "advance-v1.3"],
      "is_preview": false
    },
    {
      "id": "1.0.2_status-tab-updates",
      "hardware": ["basic", "advance-v1.3"],
      "is_preview": true
    }
  ],
  "hardware_info": {
    "basic": "Basic (4MB flash, PWM backlight)",
    "advance-v1.3": "Advance v1.3 (16MB flash, IPS display)",
    "advance-v1.2": "Advance v1.2 (older revision)"
  }
}
```

## Local Development

### Build Commands

```powershell
# Default local build (legacy path: web/firmware/basic/, web/firmware/advance/)
.\scripts\build-web-installer.ps1

# Versioned stable release
.\scripts\build-web-installer.ps1 -Version "1.0.2" -UpdateVersions

# Preview build with automatic branch name
.\scripts\build-web-installer.ps1 -Preview -UpdateVersions

# Clean build
.\scripts\build-web-installer.ps1 -Clean -Version "1.0.2" -UpdateVersions

# Start local test server
.\scripts\build-web-installer.ps1 -StartServer
```

### Testing Locally

1. Build firmware with version:
   ```powershell
   .\scripts\build-web-installer.ps1 -Version "1.0.2-test" -UpdateVersions
   ```

2. Start local server:
   ```powershell
   .\scripts\build-web-installer.ps1 -StartServer
   ```

3. Open browser to `http://localhost:8000`

4. Select version and hardware from dropdowns

5. Connect ESP32-S3 device and flash

## GitHub Actions Workflows

### Stable Releases (build-firmware.yml)

- **Trigger**: Git tags matching `v*.*.*` (e.g., `v1.0.2`)
- **Output**: `firmware/{version}/basic/` and `firmware/{version}/advance/`
- **versions.json**: Prepends new version, sets as default
- **Deployment**: GitHub Pages at root

### Preview Builds (build-branch-preview.yml)

- **Trigger**: Pushes to `feature/**`, `fix/**`, `dev` branches
- **Version ID**: `{base_version}_{branch_suffix}` (e.g., `1.0.2_status-tab-updates`)
- **Output**: `firmware/preview/{branch_suffix}/basic/` and `firmware/preview/{branch_suffix}/advance/`
- **versions.json**: Replaces existing preview with same ID
- **Deployment**: GitHub Pages at root

## Manifest Paths

The web installer dynamically loads manifests based on selection:

```
firmware/{version}/manifest_basic.json
firmware/{version}/manifest_advance.json
firmware/preview/{version}/manifest_basic.json
firmware/preview/{version}/manifest_advance.json
```

**Note**: Manifests are currently **NOT** generated automatically. They must be copied or created manually in each version folder if needed. The current implementation uses hardcoded manifest references in `index.html`.

## Version Lifecycle

1. **Development**: Work on feature branch
   - Preview builds deploy automatically on push
   - Accessible via dropdown with orange "(Preview)" badge

2. **Release**: Create git tag
   - Stable build deploys automatically
   - Added to versions.json as default
   - Preview for same base version remains available

3. **Rollback**: Users can select older versions
   - All versions preserved indefinitely
   - No automatic cleanup

## Hardware Variants

### Current Variants

- **basic**: Elecrow CrowPanel 7" Basic (4MB flash, PWM backlight)
- **advance-v1.3**: Elecrow CrowPanel 7" Advance v1.3 (16MB flash, IPS display)
- **advance-v1.2**: Elecrow CrowPanel 7" Advance v1.2 (older revision) - **Not yet implemented**

### Adding New Hardware

1. Add variant to `hardware_info` in versions.json
2. Update workflows to build new variant
3. Update `index.html` hardware descriptions
4. Create manifest for new hardware

## Fallback Behavior

If `versions.json` fails to load or is missing:

- Web installer falls back to legacy mode
- Uses root-level `manifest_basic.json` and `manifest_advance.json`
- Hardware cards remain functional
- No version selection available

## Troubleshooting

### Version not appearing in dropdown

- Check versions.json syntax (valid JSON)
- Ensure version entry has required fields: `id`, `hardware`, `is_preview`
- Verify firmware files exist at expected paths

### Manifest 404 errors

- Verify version folder structure matches dropdown paths
- Check that manifest files exist in version directories
- Inspect browser console for exact failed path

### Preview not marked as preview

- Ensure version ID contains underscore (e.g., `1.0.2_branch`)
- Or set `is_preview: true` explicitly in versions.json

### Local server CORS issues

- Use `python -m http.server 8000` or equivalent
- Do NOT use `file://` protocol
- ESP Web Tools requires HTTP/HTTPS

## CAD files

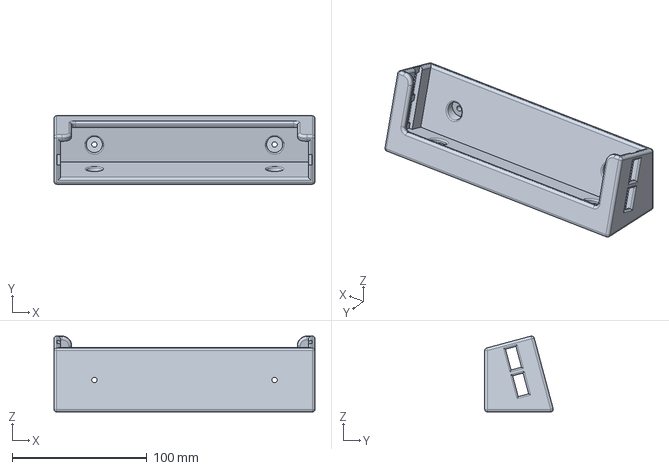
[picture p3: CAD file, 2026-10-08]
hardware/stand/CrowPanelAdvance7Stand.FCStd
194.0 x 51.0 x 56.5 mm

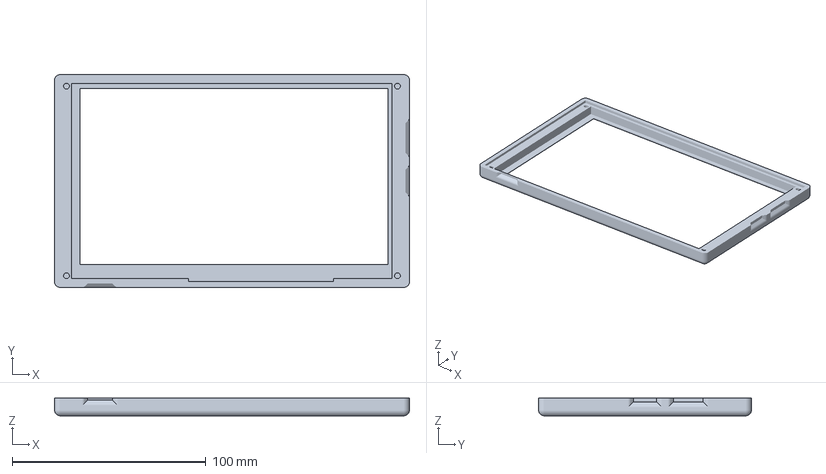
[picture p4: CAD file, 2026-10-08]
hardware/case/CrowPanelAdvance7Case-Top.3mf
183.4 x 110.0 x 9.10 mm

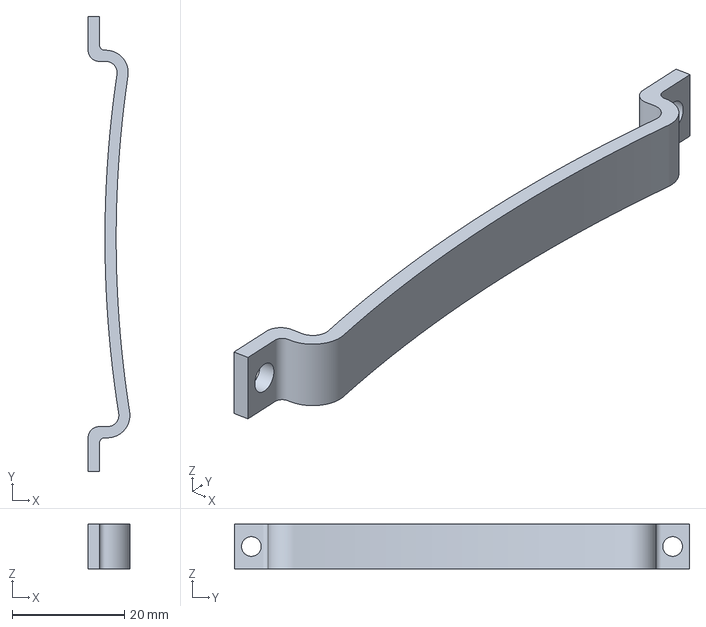
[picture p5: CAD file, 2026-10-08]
hardware/case/CrowPanelAdvance7Case-BatteryBracket.3mf
7.45 x 81.0 x 8.00 mm

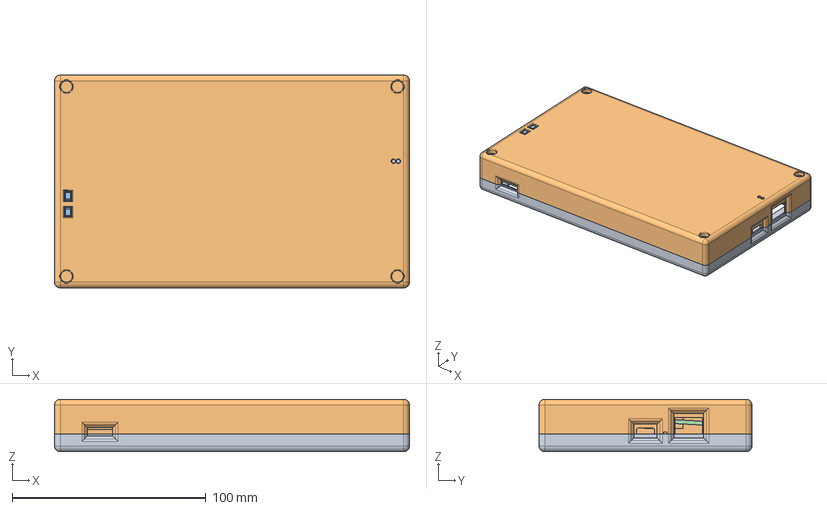
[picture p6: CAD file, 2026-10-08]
hardware/case/CrowPanelAdvance7Case.FCStd
183.4 x 110.0 x 27.1 mm
Top
Bottom
Button-v1.4 x 2
BatteryBracket x 2

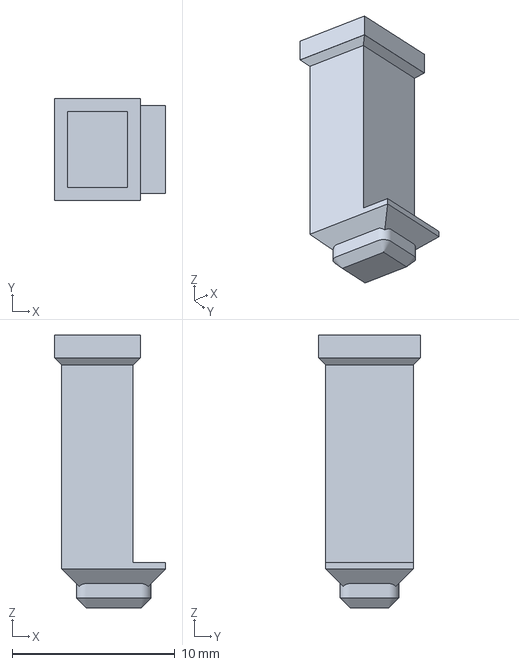
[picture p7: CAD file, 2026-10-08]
hardware/case/CrowPanelAdvance7Case-Button-v1.4.3mf
6.85 x 6.30 x 16.8 mm

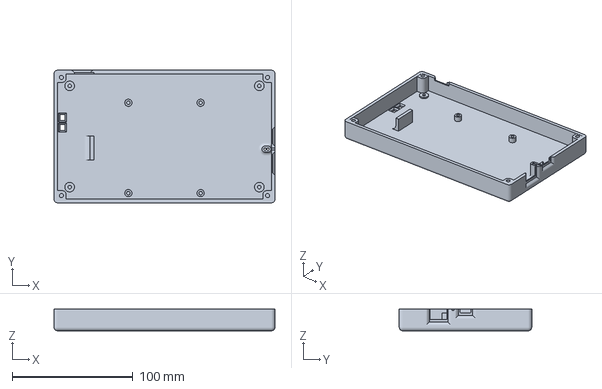
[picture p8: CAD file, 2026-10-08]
hardware/case/CrowPanelAdvance7Case-Bottom.3mf
183.4 x 110.0 x 18.0 mm

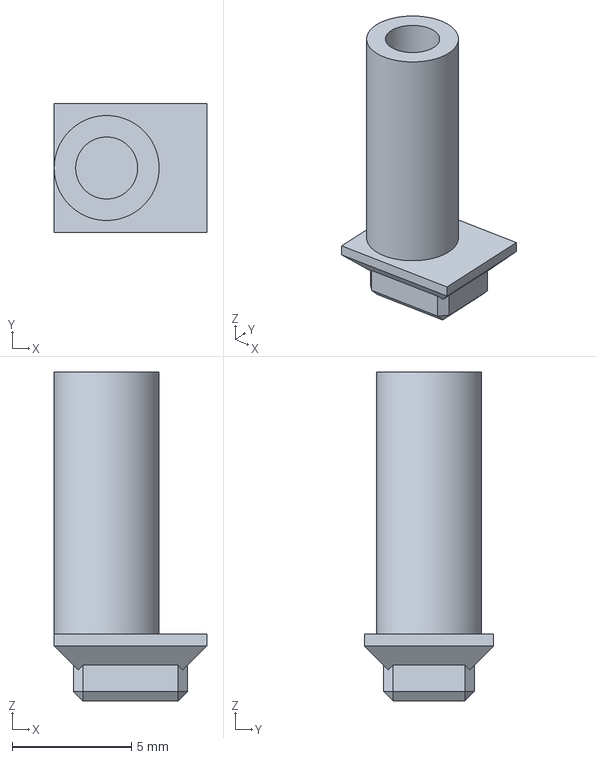
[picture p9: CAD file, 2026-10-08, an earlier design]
hardware/case/CrowPanelAdvance7Case-Button-v1.3.3mf
6.40 x 5.40 x 13.8 mm

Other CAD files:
hardware/case/CrowPanelAdvance7Case-BatteryBracket.stl
hardware/case/CrowPanelAdvance7Case-Bottom.stl
hardware/case/CrowPanelAdvance7Case-Button-v1.3.stl
hardware/case/CrowPanelAdvance7Case-Button-v1.4.stl
hardware/case/CrowPanelAdvance7Case-Top.stl
hardware/stand/CrowPanelAdvance7Stand.3mf
hardware/stand/CrowPanelAdvance7Stand.stl

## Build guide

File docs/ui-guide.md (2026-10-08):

# FluidTouch User Interface Guide

> Comprehensive walkthrough of the FluidTouch interface with screenshots

## Table of Contents

- [Startup](#startup)
- [Machine Selection](#machine-selection)
- [Main Interface](#main-interface)
  - [Status Bar](#status-bar)
  - [Tab Navigation](#tab-navigation)
- [Status Tab](#status-tab)
- [Control Tab](#control-tab)
  - [Actions](#actions)
  - [Jog](#jog)
  - [Joystick](#joystick)
  - [Probe](#probe)
  - [Overrides](#overrides)
- [Files Tab](#files-tab)
- [Macros Tab](#macros-tab)
- [Terminal Tab](#terminal-tab)
- [Settings Tab](#settings-tab)
  - [General](#general)
  - [Jog](#jog-settings)
  - [Probe](#probe-settings)
  - [WCS](#wcs-settings)
  - [Power](#power-settings)
  - [About](#about)

---

## Startup

### Splash Screen

Splash Screen

On startup, FluidTouch displays a splash screen before proceeding to machine selection.

---

## Machine Selection

Machine Selection

The machine selection screen appears after the splash screen when you first power on FluidTouch. It displays all configured machines (up to 4) with their names, WiFi networks, and connection status. Tap any machine to connect.

If no machines are configured, you'll see a prompt to add your first machine.

Each machine configuration stores:
- Machine name
- Connection type (currently only Wireless is supported)
- WiFi SSID and password
- FluidNC IP address or hostname
- WebSocket port (default: 81)

### Machine Selection Edit Mode

Machine Selection Edit Mode

Clicking the "Edit" button enters edit mode, which allows you to reorder, edit, or delete machines:

- **Layout**: Machine buttons (458px wide) on the left, control buttons (60×60px) on the right
- **Control buttons**: Up/down arrows for reordering, edit (✏️) for configuration, delete (🗑️) for removal
- **Add button**: Green "➕ Add" button (120×45px) in upper right corner appears in edit mode
- **Spacing**: Consistent 5px gaps between all elements (matches macro list spacing)
- **Workflow**: Manage → configure slots → tap machine to exit edit mode and connect

### Machine Add/Edit Dialog

Machine Add/Edit Dialog

Modal dialog for adding or editing machine configurations:

**Left Column (64% width):**
- **Name:** Machine identifier (32 characters max)
- **SSID:** WiFi network name
- **FluidNC URL:** IP address or hostname (e.g., 192.168.1.100 or fluidnc.local)

**Right Column (33% width):**
- **Connection:** Wireless (only option currently)
- **Password:** WiFi password
- **Port:** WebSocket port (default: 81)

**Buttons:**
- **Save** (bottom left) - Save configuration
- **Cancel** (bottom right) - Discard changes

---

## Main Interface

### Status Bar

Status Bar

The status bar at the top displays:

**Left Section** (clickable - navigates to Status tab):
- Machine state: IDLE, RUN, JOG, HOLD, ALARM, etc.
- Color-coded for quick recognition

**Center Section**:
- Work Position (WPos) - Orange labels
- Machine Position (MPos) - Cyan labels
- Format: X/Y/Z coordinates with axis-specific colors

**Right Section** (clickable - restart to switch machines):
- Machine name with connection symbol (top line, blue)
- WiFi network name (bottom line, cyan)

---

## Status Tab

Status Tab

Real-time machine status display with four columns:

**Column 1 - Work Position:**
- X, Y, Z (and optionally A) coordinates in work coordinate system

**Column 2 - Machine Position:**
- X, Y, Z (and optionally A) coordinates in machine coordinate system

**Column 3 - Rates:**
- Feed Rate with override percentage
- Spindle Speed with override percentage

**Column 4 - Modal States:**
- Work Coordinate System (G54-G59)
- Plane (G17/G18/G19)
- Distance Mode (G90/G91)
- Units (G20/G21)
- Motion Mode (G0/G1/G2/G3)
- Feed Mode (G93/G94)
- Spindle State (M3/M4/M5)
- Coolant (M7/M8/M9 — shows both M7 and M8 when active simultaneously)
- Tool Number

**Pin Status Indicators:**
- **Probe** indicator — lights up when the probe pin is active
- **Limit X / Y / Z (and A)** indicators — light up per axis when a limit switch is triggered
- Indicators remain visible for at least 500ms after deactivation so brief activations are easy to see

### SD Card File Progress
(while running a job)

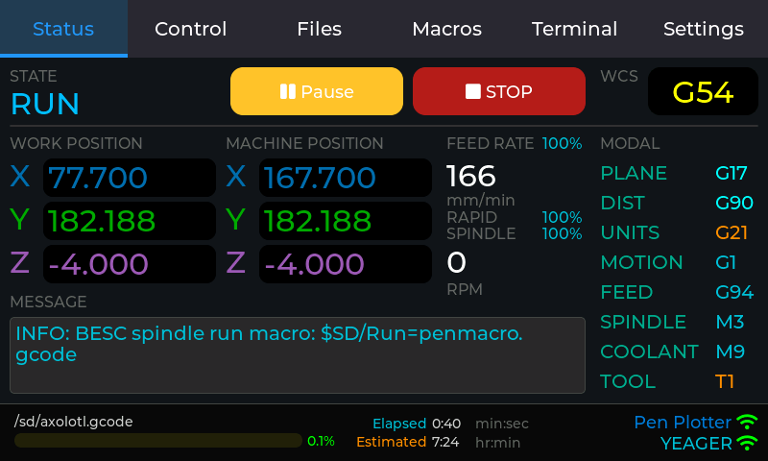
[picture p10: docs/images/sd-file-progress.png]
SD File Progress


- Filename (truncated to fit)
- Progress bar (0-100%)
- Elapsed time (H:MM format)
- Estimated completion time

**Message Display:**
- Last FluidNC message
- Spans columns 1-3 at bottom

### Jog to Position

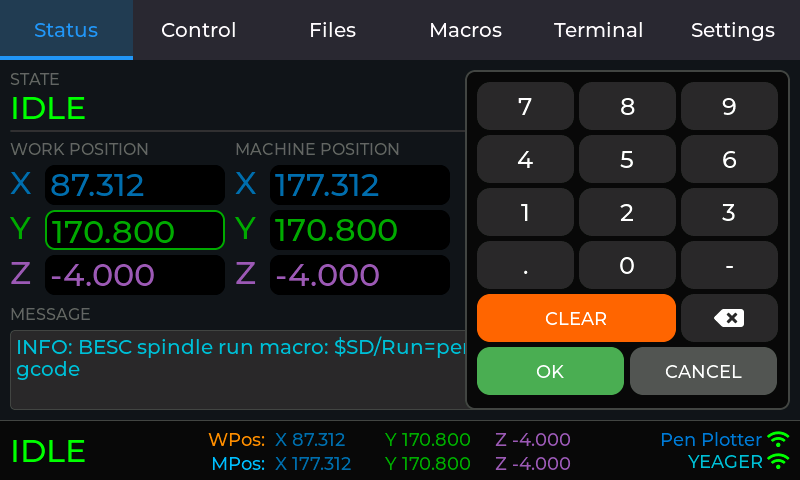
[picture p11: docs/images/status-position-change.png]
Status Position Change


- Select an X/Y/Z field in work or machine position
- Clicking OK will jog to that position

### Change Work Coordinate System (WCS)

Touching the WCS field in the upper right, will display this screen of the WCS coordinates.

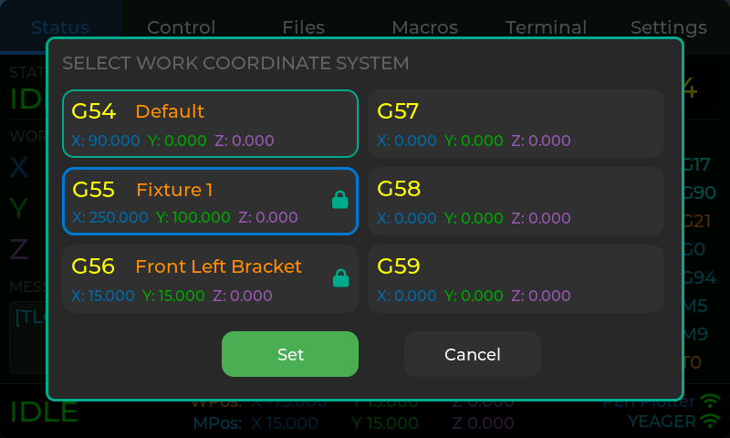
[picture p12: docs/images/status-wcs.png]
Status WCS


Selecting the WCS and touching the Set button will activate that WCS.

**WCS Lock Warning:**

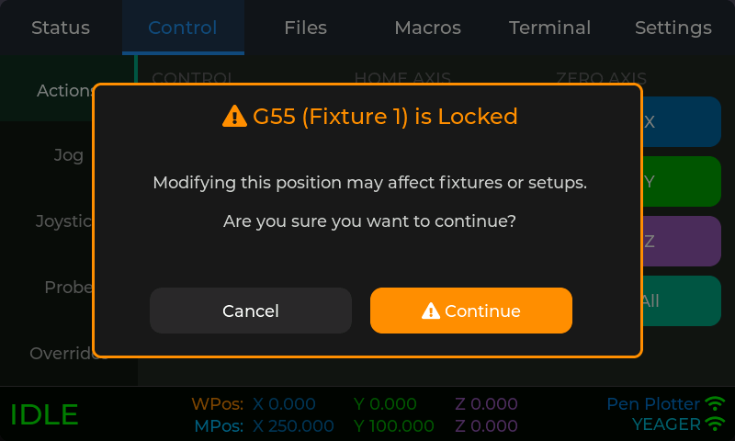
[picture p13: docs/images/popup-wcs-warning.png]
WCS Warning Popup


If attempting to probe or zero while a locked WCS is active, a warning popup appears requiring confirmation.

---

## Control Tab

The Control tab contains five sub-tabs for different control operations:

### Actions

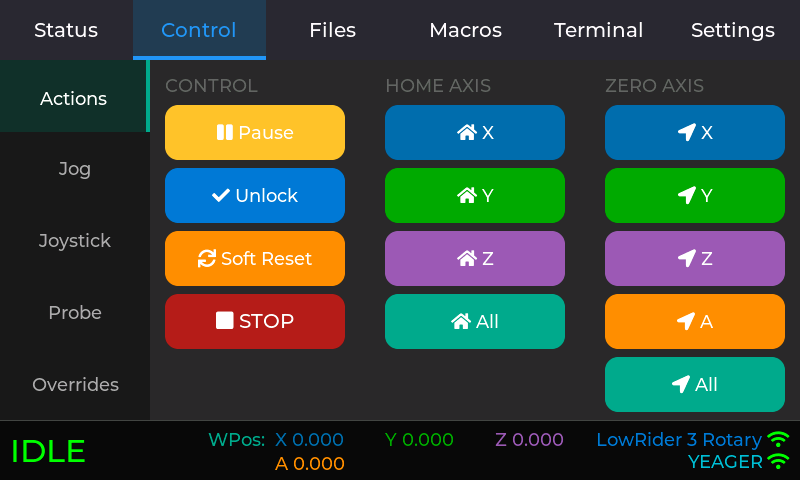
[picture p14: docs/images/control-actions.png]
Control Actions


Machine control buttons:
- **Home All** - Execute homing cycle ($H)
- **Home X/Y/Z** - Home individual axes
- **Zero All** - Zero all work coordinates (G10 L20 P0 X0 Y0 Z0 [A0])
- **Zero X/Y/Z** - Zero individual work coordinates
- **Zero A** - Zero A-axis work coordinate (visible only when A-axis is enabled)
- **Unlock** - Clear alarm state ($X)
- **Reset** - Soft reset (Ctrl+X)

**Limit Switch Indicators:**
- Per-axis indicators (X / Y / Z, plus A when enabled) light up when a limit switch is triggered
- Indicators remain visible for at least 500ms after deactivation so brief activations are easy to see

### Jog

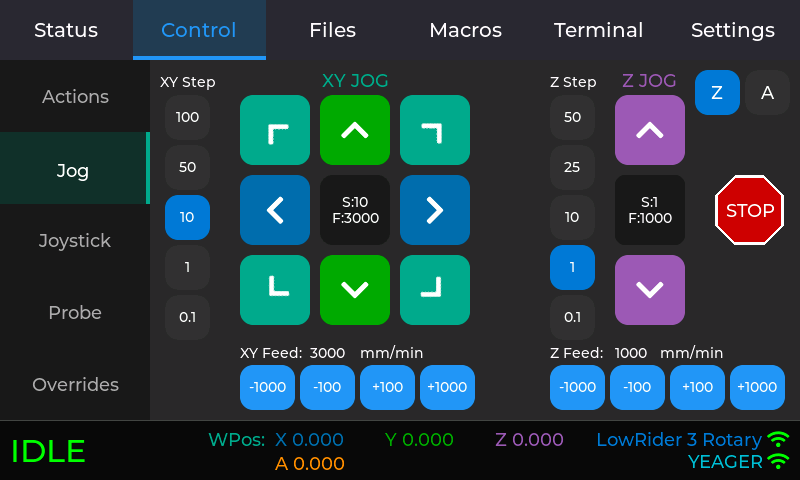
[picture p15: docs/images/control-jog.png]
Control Jog


Button-based jogging interface:

**XY Section (Left):**
- Step selection buttons (configurable in Settings → Jog, default: 100, 50, 10, 1, 0.1 mm)
- 3×3 jog pad with diagonal movements
- Axis-colored buttons (XY=cyan, Y=green, X=cyan)
- Feed rate controls (±100, ±1000 mm/min)
- Stop button

**Z Section (Right):**
- Step selection buttons (configurable in Settings → Jog, default: 50, 25, 10, 1, 0.1 mm)
- Z+ / Z- buttons (magenta)
- Feed rate controls
- Stop button (Jog Cancel)

**A Section (Right, when A-axis enabled):**
- Tab toggle: **Z** / **A** buttons to switch between Z and A jog controls
- Step selection buttons (configurable in Settings → Jog, default: 50, 25, 10, 1, 0.1)
- A+ / A- buttons (orange)
- Feed rate controls

### Joystick

Analog-style jogging with multiple axis selection modes:

**XY Mode** - Simultaneous XY movement:

Control Joystick XY

- 220×220 pixel circular pad
- Draggable knob with crosshairs
- Quadratic response curve for fine control

**XYZ Mode** - All three axes:

Control Joystick XYZ

- Circular XY pad with Z slider
- Independent control of all axes
- Z slider on right side (80×220 pixels)

**XZ Mode** - X and Z axes:

Control Joystick XZ

- Horizontal X slider
- Vertical Z slider
- Useful for face operations

**YZ Mode** - Y and Z axes:

Control Joystick YZ

- Horizontal Y slider
- Vertical Z slider
- Useful for side operations

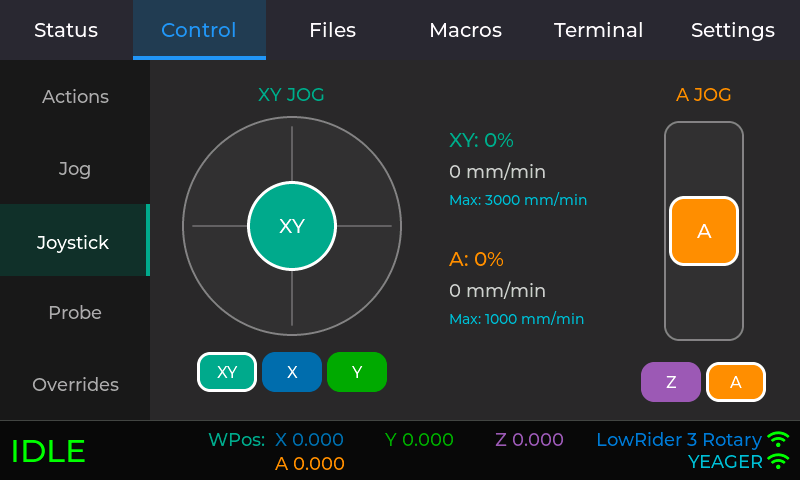
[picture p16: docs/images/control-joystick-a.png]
Control Joystick A

- Only when A-axis is enabled

**Right Slider Z/A Toggle (when A-axis enabled):**
- **Z** and **A** buttons appear above the right slider to switch between Z-axis and A-axis jogging
- Active axis shown with white border on its button

**Common Features:**
- Mode buttons below joystick with white border on selected mode
- Quadratic response curve for precise control near center
- Info display shows: current percentage (X/Y/Z/A), feed rate (mm/min), max feed rate from settings

### Probe

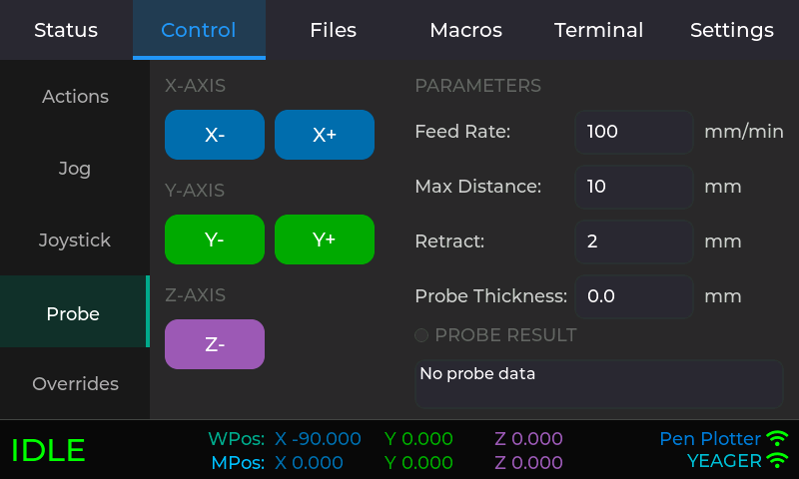
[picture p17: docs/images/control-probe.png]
Control Probe


Touch probe operations:

**Probe Buttons:**
- X-, Y-, Z- directions (axis-colored)
- Z- only for standard touch probe

**Parameters:**
- Feed Rate (mm/min)
- Max Distance (mm)
- Retract (mm)
- Probe Thickness (mm)

**Results Display:**
- Two-line result textarea
- Shows probed axis value
- Success/failure message

**Probe Indicator:**
- A probe pin indicator lights up whenever the probe input is active
- Stays visible for at least 500ms after deactivation so brief contacts are easy to see

### Overrides

Control Overrides

Real-time override controls:
- **Feed Override** - 10-200% (±10%, ±1%, Reset 100%)
- **Rapid Override** - 25/50/100% (preset buttons)
- **Spindle Override** - 10-200% (±10%, ±1%, Reset 100%)

---

## Files Tab

Files Tab

Browse and manage files on FluidNC SD card and flash storage:

**Features:**
- Navigate folders (tap to open)
- View file sizes
- Play files (GCode programs)
- Upload files from browser
- Delete files and folders

**File List:**
- Shows folders and files from current directory
- Folders appear first (if "Folders on Top" enabled)
- File sizes displayed for files
- Back button to navigate to parent directory

### File Upload Dialog

File Upload Dialog

Modal dialog for uploading files to FluidNC:

**Steps:**
1. Tap "Upload" button in Files tab
2. Dialog shows current directory path
3. Displays web URL with QR code
4. Open URL in browser on computer/phone
5. Select file to upload
6. Progress bar shows upload status
7. File appears in file list when complete

**Upload Progress:**
- Shows current/total bytes transferred
- Percentage complete
- Progress bar visual
- "Reset device to cancel upload" during transfer
- "Close" button after completion

### Delete Confirmation

File Delete Dialog

Confirmation dialog before deleting files:
- Shows filename to be deleted
- "Delete" button (red) - Confirm deletion
- "Cancel" button (gray) - Abort operation

---

## Macros Tab

Macros Tab

Store and execute up to 9 file-based macros:

**Normal Mode:**
- 3×3 grid of macro buttons
- Tap to execute macro file
- Color-coded for quick identification
- Empty slots show "Empty"
- Gear icon (upper right) to enter edit mode

### Macro Edit Mode

Macros Edit Mode

Configure all 9 macro slots simultaneously:

**Layout:**
- 3×3 grid matching normal mode layout
- Each slot shows: macro button, edit button, delete button
- "Done" button (upper right) to exit edit mode

**Per-Slot Controls:**
- **Macro Button:** Preview with current name/color
- **Edit Button:** Opens configuration dialog for that slot
- **Delete Button:** Removes macro configuration (slot becomes "Empty")

**Workflow:**
1. Tap gear icon to enter edit mode
2. Tap edit button on any slot to configure
3. Set name, select file, choose color in dialog
4. Save to apply changes
5. Tap "Done" to return to normal mode

### Macro Configuration Dialog

Macro Config Dialog

Modal dialog for configuring individual macros:

**Fields:**
- **Name:** Macro display name (shown on button)
- **File:** Dropdown of available macro files from `/sd/FluidTouch/Macros/`
- **Color:** Color picker for button background

**Buttons:**
- **Save** - Save macro configuration
- **Cancel** - Discard changes

**Notes:**
- Macro files must be placed in `/sd/FluidTouch/Macros/` directory on FluidNC
- Files should contain valid GCode commands
- Common macros: warm-up routines, homing sequences, tool changes

---

## Terminal Tab

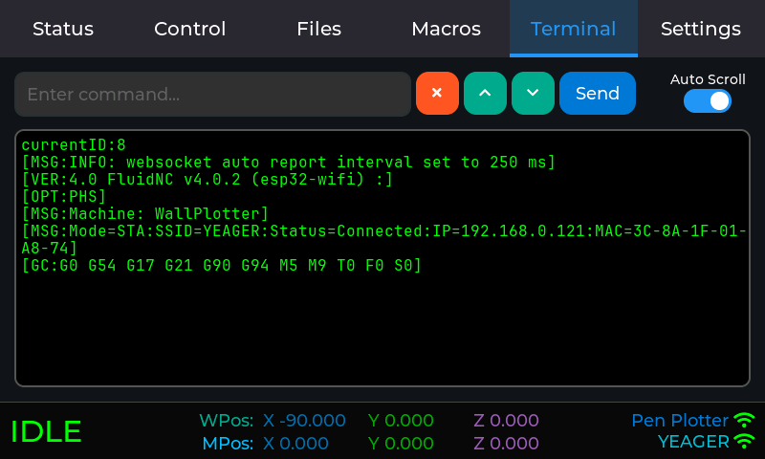
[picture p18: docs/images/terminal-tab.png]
Terminal Tab


Raw WebSocket message display:
- Live message stream from FluidNC
- Auto-scroll toggle
- Excludes messages such as status updates to prevent performance issues.

**Command History:**
- Up / Down arrow buttons next to the input field recall previously sent commands
- Stores the most recent 10 unique commands; consecutive duplicates are skipped
- History is kept while the controller is running (cleared on restart)

---

## Settings Tab

The Settings tab contains six sub-tabs for configuration:

### General

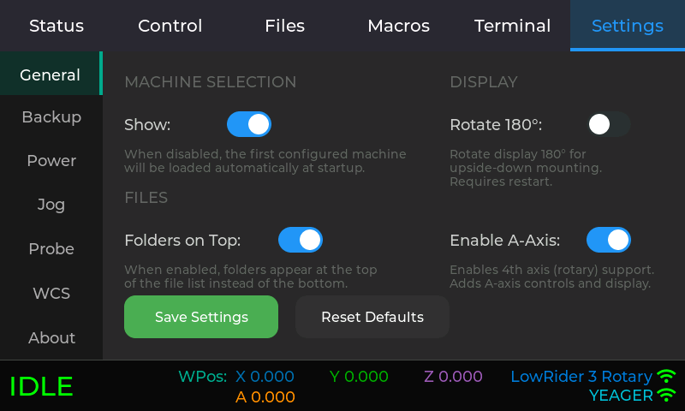
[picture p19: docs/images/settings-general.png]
Settings General


**Machine Selection:**
- Whether or not to show the machine selection screen. If skipped, it will automatically load the last machine used (or the first machine, if none has been used yet). This suits a display that's wired to one machine: select it once, then turn this off.

**File Browser:**
- **Folders on Top:** When enabled, folders appear first in the Files tab, followed by files (both sorted alphabetically)

**Rotate 180 degrees**
- Whether or not to rotate the screen 180 degrees.

**Enable A-Axis:**
- When enabled, a 4th A-axis is shown in the status bar, Status tab, Jog tab, Joystick tab, and Actions tab.
- Setting is **per-machine** — the toggle applies to the currently selected machine, allowing mixed 3-axis and 4-axis configurations.
- Requires a restart to take effect after changing.

### Backup

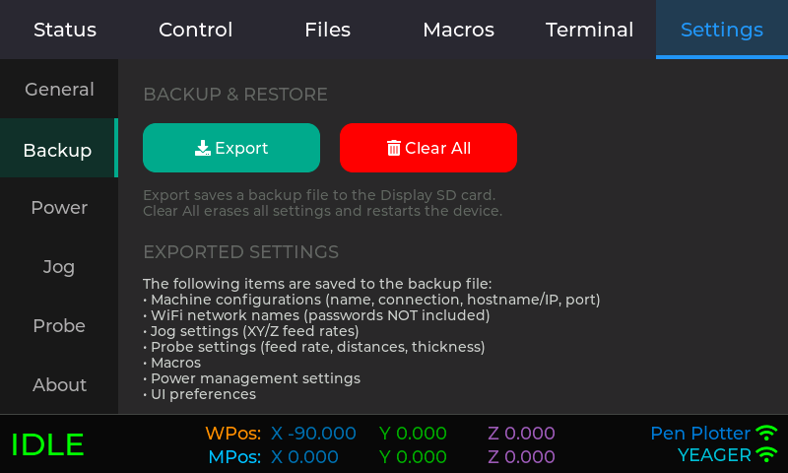
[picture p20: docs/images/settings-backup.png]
Settings Backup


- **Export Settings:** Creates `/fluidtouch_settings.json` on Display SD card
  - Includes all machine configurations, jog/probe settings, macros, power settings, and UI preferences
  - **Security Note:** WiFi passwords are NOT included in the export for security reasons
  - When importing settings, you'll need to manually set WiFi passwords for each machine
- **Clear All Settings:** Permanently deletes all settings and restarts the controller
  - Removes all machines, macros, power settings, and preferences
  - **Warning:** This action cannot be undone
  - Consider exporting settings before clearing

**Import Settings:**
- Automatic: If no machines are configured on boot and `/fluidtouch_settings.json` exists on Display SD, settings are automatically imported
- Manual: Copy settings file to Display SD root, Clear All Settings, restart to trigger import

### Jog Settings

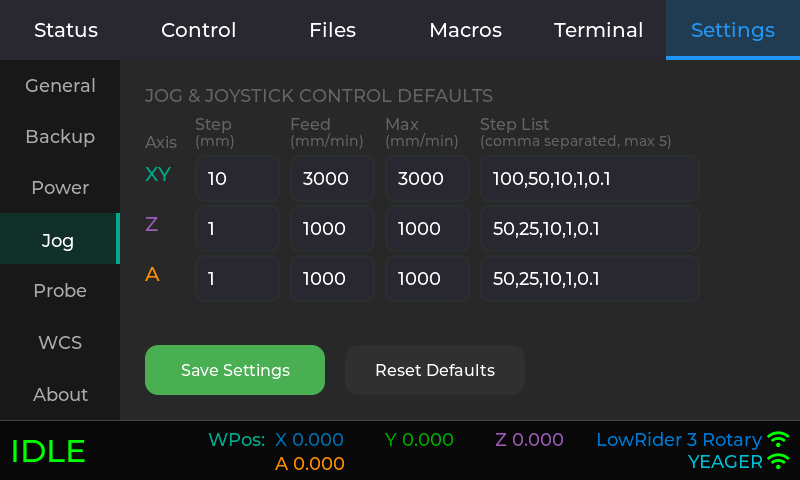
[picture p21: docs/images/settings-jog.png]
Settings Jog


Jogging preferences:
- **XY Max Feed Rate** (mm/min) - maximum speed for XY jogging and joystick
- **Z Max Feed Rate** (mm/min) - maximum speed for Z-axis jogging and joystick
- **A Max Feed Rate** (mm/min) - maximum speed for A-axis jogging and joystick (visible when A-axis enabled)
- **XY Steps** - comma-separated list of step button values for XY jogging (e.g., `100,50,10,1,0.1`)
- **Z Steps** - comma-separated list of step button values for Z jogging
- **A Steps** - comma-separated list of step button values for A jogging (visible when A-axis enabled)

### Probe Settings

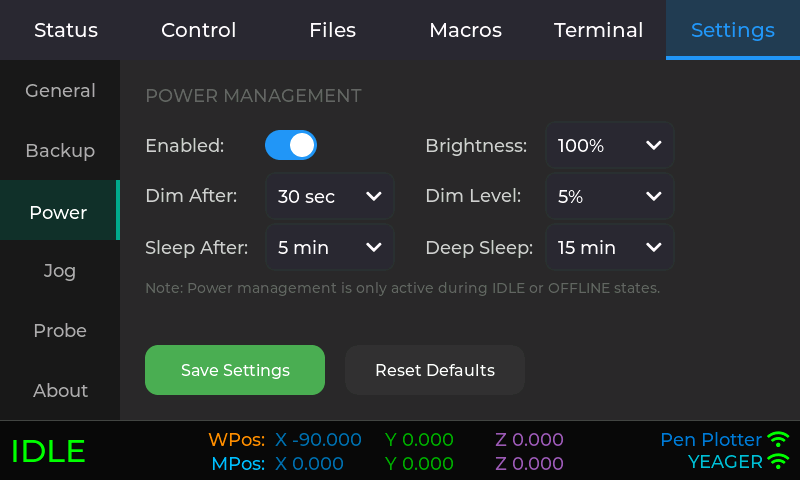
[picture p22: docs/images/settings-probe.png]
Settings Probe


Probe operation defaults:
- Feed Rate (mm/min)
- Max Distance (mm)
- Retract Distance (mm)
- Probe Thickness (mm)

### WCS Settings

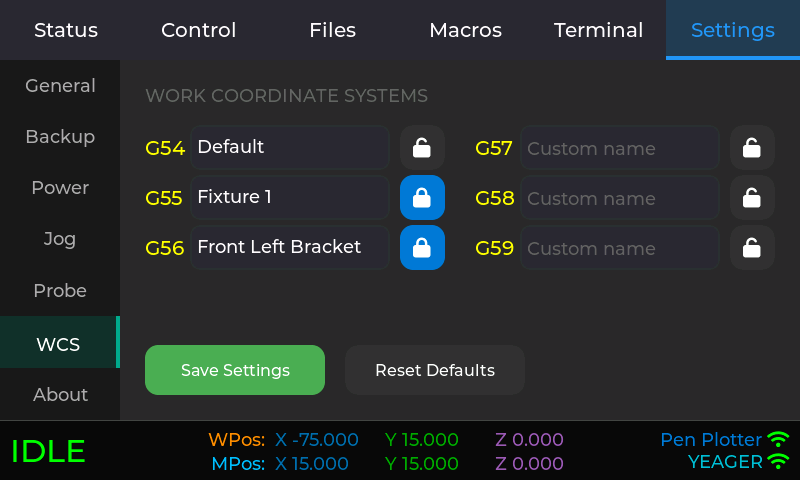
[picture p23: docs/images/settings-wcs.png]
Settings WCS


Work Coordinate System configuration:
- **Custom Name:** Provide meaningful name to a WCS
- **Lock WCS:** Prevent accidental changes to selected work coordinate system

### Power Settings

Settings Power

Power management and display brightness:

**Power Management:**
- **Enable/Disable:** Toggle power saving features
- **Dim Timeout:** Time until screen dims (Disabled, 15s-300s)
- **Sleep Timeout:** Time until screen off (Disabled, 60s-3600s)
- **Deep Sleep:** Time until deep sleep (Disabled, 5min-90min)

**Brightness Control:**
- **Normal Brightness:** Active display brightness (25%, 50%, 75%, 100%)
- **Dim Brightness:** Dimmed display brightness (5%, 10%, 25%, 50%)

**Notes:**
- Power saving only active during IDLE and DISCONNECTED states
- Touch activity resets timers and restores full brightness
- Deep sleep requires reset button to wake

### About

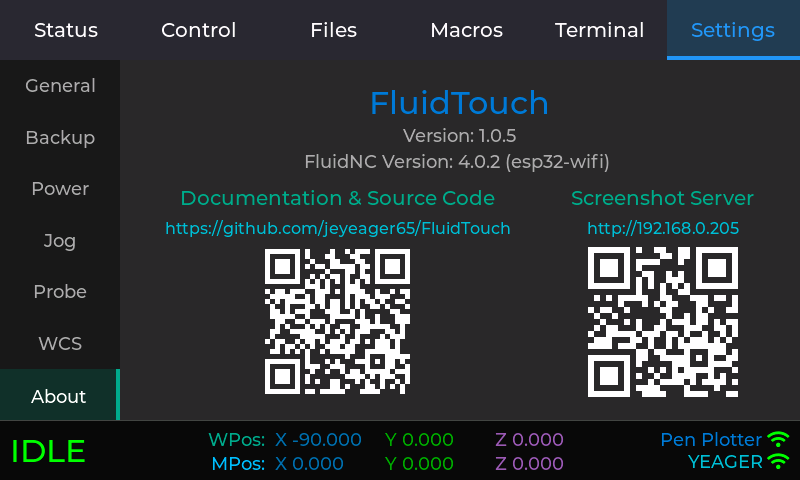
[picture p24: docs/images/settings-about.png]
Settings About


Project information:
- FluidTouch version
- FluidNC controller firmware version (shown when connected)
- GitHub link with QR code
- Screenshot server link with QR code

**GitHub QR Code:**
- Points to repository

**Screenshot Server QR Code:**
- Appears when WiFi connects
- Shows http://[IP] URL

---

## Popups & Dialogs

### System Options Popup

System Options

Appears when clicking the right side of status bar while connected:

- **Title:** System Options
- **Message:** "Restart to change machines" (or with power off note if power management enabled)
- **Buttons:**
  - Restart - Restarts ESP32 to return to machine selection
  - Power Off - Deep sleep mode (only if power management enabled)
  - Cancel - Closes dialog

### Connection Error Popups

**Machine Disconnected Popup:**

Machine Disconnected

Appears when connection is lost after being previously connected:

- **Title:** Machine Disconnected
- **Message:** Shows connection details (machine name, URL, error info)
- **Buttons:**
  - Connect - Attempts to reconnect
  - Restart - Restarts ESP32
  - Close - Dismisses dialog

**Machine Connection Failed Popup:**

Machine Connection Failed

Appears when initial connection attempt fails or when clicking status bar while disconnected:

- **Title:** Connection Lost or Machine Connection Failed
- **Message:** Shows connection details and failure reason
- **Buttons:**
  - Connect - Attempts to reconnect
  - Restart - Restarts ESP32
  - Close - Dismisses dialog

### State Popups

**HOLD Popup:**

HOLD Popup

- Appears when machine enters HOLD state
- Shows last FluidNC message
- Buttons: "Close" (dismiss) and "Resume" (send cycle start)

**ALARM Popup:**

ALARM Popup

- Appears when machine enters ALARM state
- Shows alarm message
- Buttons: "Close" (dismiss) and "Clear Alarm" (reset + unlock)

---

## Navigation Tips

- **Tap status bar left** - Jump to Status tab
- **Tap status bar right** - Restart to switch machines
- **State popups** - Auto-dismiss when state changes
- **QR codes** - Scan with phone camera for quick links
- **Position displays** - Updated every 250ms from FluidNC

---

*For detailed operating instructions, see [Usage Guide](./usage.md)*

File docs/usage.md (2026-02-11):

# FluidTouch Usage Guide

> Step-by-step instructions for operating your CNC machine with FluidTouch

## Table of Contents

- [First-Time Setup](#first-time-setup)
- [Importing Settings](#importing-settings)
- [Connecting to Your Machine](#connecting-to-your-machine)
- [Basic Operations](#basic-operations)
- [Jogging](#jogging)
- [Probing](#probing)
- [Running Jobs](#running-jobs)
- [Troubleshooting](#troubleshooting)

---

## First-Time Setup

### 1. Power On

Connect the display to power via USB-C or external power supply. The device will boot and show the FluidTouch splash screen.

### 2. Configure WiFi

1. After splash screen, you'll see the machine selection screen
2. If no machines are configured, add your first machine
3. Go to **Settings → General**
4. Enter your **WiFi SSID** and **Password**
5. Tap **Connect**
6. Wait for "Connected" status (shows IP address)

### 3. Add Your Machine

1. Return to machine selection (restart if needed)
2. Tap the **green "Add Machine"** button
3. Enter machine details:
   - **Name:** Friendly name (e.g., "CNC Router", "Laser")
   - **Hostname/IP:** FluidNC IP address (e.g., `192.168.1.100`)
   - **Port:** WebSocket port (default: `81`)
     - Port 80 for FluidNC v4.0+
     - Port 81 for FluidNC v3.x (WebUI v2)
     - Port 82 for FluidNC v3.x (WebUI v3)
4. Tap **Save**
5. Select the machine to connect

### 4. Verify Connection

Check the status bar:
- **Left:** Should show machine state (IDLE, ALARM, etc.)
- **Center:** Shows position coordinates
- **Right:** Shows machine name and WiFi network

If showing ALARM, clear it: **Control → Actions → Unlock**

---

## Importing Settings

If you have a settings backup file from another FluidTouch device or a previous installation:

### Automatic Import on Boot

1. Copy `fluidtouch_settings.json` to the root of your Display SD card
2. Power on FluidTouch (with no machines configured)
3. Settings are automatically imported during startup
4. Device restarts after successful import
5. **Important:** Re-enter WiFi passwords for each machine (passwords are not included in backups for security)

### Manual Import After Setup

1. Copy `fluidtouch_settings.json` to Display SD card root
2. Go to **Settings → General**
3. Tap **Clear All Settings** button
4. Confirm the warning dialog
5. Device restarts and auto-imports settings
6. Configure WiFi passwords for wireless machines

### After Import

1. Check each machine configuration
2. Enter WiFi passwords (Settings → Machine Selection → Edit)
3. Test connection to each machine
4. Verify jog/probe settings are correct
5. Check that macros are properly loaded

---

## Connecting to Your Machine

### Machine Selection

On startup, FluidTouch shows saved machines:
1. **Tap a machine** to connect
2. **Edit** button - Modify machine settings
3. **Delete** button - Remove machine
4. **Up/Down** buttons - Reorder machines
5. **Add** button (green) - Add new machine

### Switching Machines

1. Tap **right side of status bar** (machine name area)
2. Confirm restart dialog
3. Device restarts and shows machine selection
4. Select different machine

---

## Basic Operations

### Understanding Machine States

FluidTouch displays the current machine state in the status bar (left side):

- **IDLE** (Green) - Ready for commands
- **RUN** (Cyan) - Executing G-code
- **JOG** (Cyan) - Manual jogging active
- **HOLD** (Yellow) - Feed hold (paused)
- **ALARM** (Red) - Error state, requires clearing
- **CHECK** (Orange) - G-code check mode
- **HOME** (Blue) - Homing cycle active
- **SLEEP** (Gray) - Sleep mode

### Clearing Alarms

If the machine enters ALARM state:

**Method 1 - Use Popup:**
1. ALARM popup appears automatically
2. Tap **Clear Alarm** button
3. Wait for state to change to IDLE

**Method 2 - Use Actions Tab:**
1. Go to **Control → Actions**
2. Tap **Unlock** button
3. If needed, tap **Reset** to fully restart

### Homing the Machine

Before first use, home your machine:

1. Go to **Control → Actions**
2. Tap **Home All** to home all axes
3. Or tap individual **Home X/Y/Z** buttons
4. Wait for homing cycle to complete
5. Status bar shows "IDLE" when done

---

## Jogging

### Button-Based Jogging (Jog Tab)

**XY Jogging:**
1. Go to **Control → Jog**
2. Select **step size** (100, 50, 10, 1, 0.1 mm)
3. Tap **direction buttons** on jog pad
   - Diagonal buttons move both axes
   - N/S buttons move Y only
   - E/W buttons move X only
4. Adjust **feed rate** with ±100 / ±1000 buttons
5. Tap **STOP** to cancel movement

**Z Jogging:**
1. Select **Z step size** (50, 25, 10, 1, 0.1 mm)
2. Tap **Z+** or **Z-** buttons
3. Adjust **feed rate** independently
4. Tap **STOP** to cancel

### Analog Jogging (Joystick Tab)

**XY Joystick:**
1. Go to **Control → Joystick**
2. Drag the **circular joystick** knob
3. Distance from center = speed (quadratic response)
4. Release to stop

**Z Slider:**
1. Drag the **vertical slider** knob
2. Up = Z+, Down = Z-
3. Distance from center = speed
4. Release to stop

**Feed Rate:**
- Set max feed rates in **Settings → Jog**
- Joystick/slider position scales from 0% to 100% of max

---

## Probing

### Setting Up Touch Probe

1. Attach touch probe to spindle/tool holder
2. Connect probe wire to FluidNC
3. Go to **Control → Probe**
4. Configure parameters:
   - **Feed Rate:** Probe speed (default: 100 mm/min)
   - **Max Distance:** How far to search (default: 50 mm)
   - **Retract:** Pull-off distance after contact (default: 2 mm)
   - **Probe Thickness:** Probe plate/puck thickness (default: 0 mm)

### Probing Operations

**Z-Axis Probing (Tool Length):**
1. Position tool above probe plate/work surface
2. Ensure within Max Distance
3. Tap **Z-** probe button
4. Wait for probe cycle to complete
5. Check results display:
   - "SUCCESS" - Shows Z position found
   - "FAILED" - No contact detected

**Offset Adjustment:**
- If using probe plate, enter thickness in **Probe Thickness**
- FluidTouch automatically accounts for thickness in result

---

## Running Jobs

### Before Starting

1. **Home machine** (Control → Actions → Home All)
2. **Load material** and secure workpiece
3. **Zero work coordinates:**
   - Jog to work zero position
   - Control → Actions → Zero All (or individual axes)
4. **Load G-code file** to FluidNC (via SD card or WebUI)

### Starting a Job

1. On the Files tab, start the G-code file
2. FluidTouch Status tab shows:
   - File name
   - Progress bar (0-100%)
   - Elapsed time
   - Estimated completion time
3. Monitor machine state and positions

### During a Job

**Feed Hold (Pause):**
- Press Pause button (Control → Actions)
- FluidTouch shows HOLD popup
- Tap **Resume** to continue

**Stop:**
- Press Stop button (Control → Actions)
- Not to be used as an Emergency stop

### Job Monitoring

Status tab displays:
- **Real-time positions** - Work and machine coordinates
- **Feed rate** - Current vs. programmed
- **Spindle speed** - Current vs. programmed
- **File progress** - Percentage and time remaining
- **Messages** - FluidNC feedback

---

## Troubleshooting

### WiFi Won't Connect

**Check:**
- SSID and password are correct (case-sensitive)
- WiFi network is 2.4GHz (ESP32 doesn't support 5GHz)
- Router is in range and operational

**Note:** If importing settings, WiFi passwords must be manually re-entered for security reasons.

### Can't Connect to FluidNC

**Check:**
- FluidNC is powered on and responsive
- IP address/hostname is correct
- Port is correct (80 for v4.0+, 81 for v3.x default)
- Both devices on same WiFi network
- WiFi password is configured (check machine settings)

**Try:**
- Access FluidNC WebUI from browser
- Check FluidNC YAML configuration for WebSocket port
- Restart both FluidTouch and FluidNC

### Settings Lost After Power Cycle

FluidTouch stores settings in non-volatile memory, but if settings are lost:

**Prevention:**
1. Go to **Settings → General**
2. Tap **Export Settings**
3. Keep backup file on Display SD card
4. Copy backup to computer for safekeeping

**Recovery:**
1. Insert Display SD card with `fluidtouch_settings.json`
2. Go to **Settings → General → Clear All Settings**
3. Restart triggers automatic import
4. Re-enter WiFi passwords

### Import/Export Issues

**Export Failed:**
- Ensure Display SD card is inserted
- Check SD card has free space
- Try removing and re-inserting SD card
- Restart device and try again

**Auto-Import Not Working:**
- Verify file is named exactly `fluidtouch_settings.json`
- File must be in root directory of Display SD card
- Auto-import only works when no machines are configured
- Check file is valid JSON (view in text editor)

---

*For UI details and screenshots, see [User Interface Guide](./ui-guide.md)*

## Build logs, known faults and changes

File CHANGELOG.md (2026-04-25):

# Changelog

All notable changes to FluidTouch will be documented in this file.

The format is based on [Keep a Changelog](https://keepachangelog.com/en/1.0.0/),
and this project adheres to [Semantic Versioning](https://semver.org/spec/v2.0.0.html).

## [1.0.5] - 2026-04-24

### Added

- **Probe / Limit Switch Indicators** - Real-time pin status indicators on Control tabs and Status tab
  - Probe indicator on **Control → Probe** and on the Status tab
  - Limit-switch indicators (per axis) on **Control → Actions** and on the Status tab
  - Triggered indicators remain visible for 500ms so brief activations are easy to see
- **Terminal History** - Terminal tab now retains command history; recall previous commands for re-sending
- **FluidNC Version on About Tab** - Settings → About now displays the connected FluidNC controller's firmware version
- **M7 + M8 Coolant Display** - Status tab correctly shows both flood (M8) and mist (M7) coolant when active simultaneously

### Changed

- **A-Axis Setting is Per-Machine** - A-axis enable/disable is now stored per machine instead of as a global setting, allowing mixed 3-axis and 4-axis machine configurations
- **LVGL 9.5.0** - Updated UI library from 9.4.x to 9.5.0
- **LovyanGFX 1.2.19** - Updated display driver
- **ArduinoJson 7.4.3** - Updated JSON library
- **ESP32 Platform Branch** - Switched to the `Arduino/IDF53_gcc15` branch of the Jason2866 ESP32 platform after the previous `Arduino/IDF53` branch was removed/renamed upstream

### Fixed

- **Build Compatibility** - Resolved build break caused by the LovyanGFX update

## [1.0.4] - 2026-03-23

### Added

- **A-Axis Support** - Optional 4th-axis support for rotary and A-axis machines (#34)
  - Enable/disable via **Settings → General → Enable A-Axis** (takes effect after restart)
  - A-axis position display in status bar and Status tab (orange color)
  - A-axis jog section in **Control → Jog** tab (mirrors Z-axis layout with its own step buttons)
  - Z/A toggle on the right slider in **Control → Joystick** tab when A-axis is enabled
  - **Zero A** button in **Control → Actions** when A-axis is enabled
  - A-axis max feed rate and step size configuration in **Settings → Jog**
- **Configurable Jog Steps** - Per-machine jog step button values now configurable in **Settings → Jog**
  - XY, Z, and A-axis step lists are fully customizable (comma-separated values)
  - Changes saved per machine

### Fixed

- **File List Out of Memory** - Resolved crash when browsing directories with large numbers of files (#35)
- **Message Display Filtering** - Status bar and Status tab now only show informational and error messages, reducing noise from status report data
- **Wakeup Touch Suppression** - First touch input after wake from deep sleep or display-off state no longer triggers unintended UI actions

### Changed

- **Serial Input Forwarding** - Commands entered in a serial terminal (e.g., Arduino IDE Serial Monitor at 115200 baud) are now forwarded to FluidNC for debugging convenience

## [1.0.3] - 2026-02-10

### Added

- **Advance Hardware v1.2 Support** - Added support for Elecrow CrowPanel 7" Advance v1.2 displays (⚠️ untested) (#11)
  - Note: v1.2 requires same DIP switch configuration as v1.3 (S0 and S1 both set to position 1)
- **mDNS Hostname Resolution** - Connect to FluidNC by hostname (e.g., `fluidnc.local`) instead of IP address (#26)
- **Upload Directory Auto-Creation** - Automatically creates upload directory if it doesn't exist when uploading files from Display SD
- **Open Upload Folder Button** - Quick access button to open the uploaded files folder on FluidNC
- **WCS Display Enhancements** - Improved Work Coordinate System labeling and lock status indicators

### Fixed

- **Display Flicker** - Eliminated screen flicker by migrating to ESP-IDF 5.3 and optimizing display timing parameters
- **Basic Hardware Touch Response** - Improved touch sensitivity and reliability on Basic hardware variant (#21, #23)
- **Probe After WCS Confirmation** - Fixed probe operations failing after confirming Work Coordinate System updates
- **Web Installer Caching** - Prevented browser caching of versions.json to ensure latest version list is always displayed

## [1.0.2] - 2026-01-24

### Changed

- **Status Tab Updates**
  - **Pause/Resume and Stop Buttons** - Pause/Resume/Stop from status tab (#13)
  - **Position Update on Status Tab** - Click positions on status tab to update (#14)
  - **WCS Update on Status Tab** - Click work position values to update Work Coordinate System (#15)
- **Settings Updates**
  - **Display Rotation Support** - Can now rotate display 180 degrees via Settings → General (#12)
- **Web Installer Version Selection** - Dropdown to select from multiple firmware versions including preview builds

### Fixed

- **File Upload with Spaces** - Fixed handling of filenames containing spaces in upload operations

## [1.0.1] - 2025-12-04

### Fixed

- **Touch Screen Deep Sleep Bug** - Fixed touch screen not working after deep sleep wake on Basic hardware
- **Boot Display Flash** - Fixed garbled screen flash on startup

### Changed

- **Documentation Updates** - Product links now use affiliate codes to help support development
- **Hardware Recommendation** - Advance display model now marked as recommended (superior IPS display, optional battery case)

## [1.0.0] - 2025-11-17

### Initial Release

FluidTouch 1.0.0 is the first stable release of the ESP32-S3 touchscreen CNC controller for FluidNC-based machines.

#### Features

- **Real-time Machine Control** - Monitor position, state, feed/spindle rates with live updates
- **Multi-Machine Support** - Store and switch between up to 4 different CNC configurations
- **Intuitive Jogging** - Button-based and analog joystick interfaces with configurable step sizes
- **Touch Probe Operations** - Automated probing with customizable parameters
- **Macro Support** - Configure and store up to 9 file-based macros per machine
- **File Management** - Browse and manage files from FluidNC SD, FluidNC Flash, and Display SD card
- **Settings Backup & Restore** - Export settings to JSON, auto-import on fresh install
- **Power Management** - Configurable display dimming, sleep, and deep sleep modes
- **WiFi Connectivity** - WebSocket connection to FluidNC with automatic status reporting
- **Terminal** - Execute custom commands and view FluidNC messages

#### Supported Hardware

- Elecrow CrowPanel 7" Basic ESP32-S3 HMI Display (4MB Flash + 8MB PSRAM)
- Elecrow CrowPanel 7" Advance ESP32-S3 HMI Display (16MB Flash + 8MB PSRAM)
  - Hardware Version 1.3 only

#### Documentation

- Complete user interface guide with screenshots
- Usage instructions and workflows
- Configuration guide for WiFi, machines, and settings
- Development guide for building from source

[1.0.5]: https://github.com/jeyeager65/FluidTouch/releases/tag/v1.0.5
[1.0.4]: https://github.com/jeyeager65/FluidTouch/releases/tag/v1.0.4
[1.0.3]: https://github.com/jeyeager65/FluidTouch/releases/tag/v1.0.3
[1.0.2]: https://github.com/jeyeager65/FluidTouch/releases/tag/v1.0.2
[1.0.1]: https://github.com/jeyeager65/FluidTouch/releases/tag/v1.0.1
[1.0.0]: https://github.com/jeyeager65/FluidTouch/releases/tag/v1.0.0

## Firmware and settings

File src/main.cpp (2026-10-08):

#include <Arduino.h>
#include <lvgl.h>
#include <WiFi.h>
#include <Preferences.h>
#include "config.h"                  // PREFS_NAMESPACE
#include "debug_log.h"               // Global serial-debug mute (LOG_* macros)
#include "core/display_driver.h"     // Display driver module
#include "core/touch_driver.h"       // Touch driver module
#include "core/power_manager.h"      // Power management module
#include "network/screenshot_server.h"  // Screenshot web server
#include "network/fluidnc_client.h"     // FluidNC WebSocket client
#include "ui/ui_theme.h"        // UI theme colors
#include "ui/ui_splash.h"       // Splash screen module
#include "ui/ui_machine_select.h" // Machine selection screen
#include "ui/ui_common.h"       // UI common components (status bar)
#include "ui/ui_tabs.h"         // UI tabs module
#include "ui/settings_manager.h" // Settings import/export/clear
#include "ui/tabs/ui_tab_status.h" // Status tab for updates
#include "ui/tabs/ui_tab_main.h"   // Main tab (reduced-axis machines) for updates
#include "ui/tabs/ui_tab_files.h" // Files tab for refresh check
#include "ui/tabs/ui_tab_macros.h" // Macros tab for progress updates
#include "ui/tabs/ui_tab_terminal.h" // Terminal tab for updates
#include "ui/tabs/settings/ui_tab_settings_about.h" // About tab for screenshot URL updates
#include "ui/tabs/control/ui_tab_control_actions.h" // Actions tab for pause button updates
#include "ui/tabs/control/ui_tab_control_override.h" // Override tab for updates
#include "ui/tabs/control/ui_tab_control_probe.h"   // Probe tab for probe indicator
#include "ui/machine_config.h"  // Machine configuration manager

// Global serial-debug mute flag (declared extern in debug_log.h).
// Set true by FluidNCClient while a UART / USB CDC connection owns UART0.
bool g_serialMuted = false;

// True if the last machine used connects to FluidNC over UART0 (the UART0
// header or USB CDC). The debug console is UART0 too, so anything it printed
// would go straight into FluidNC, and bytes such as '!' (feed hold) or
// 0x80-0xBF (overrides) are realtime commands to it.
static bool lastMachineUsesUart0() {
#ifdef HARDWARE_ADVANCE
    Preferences prefs;
    prefs.begin(PREFS_NAMESPACE, true);
    int index = prefs.getInt("sel_machine", -1);
    uint8_t type = CONN_WIFI;
    if (index >= 0 && index < MAX_MACHINES) {
        String key = "m" + String(index) + "_type";
        type = prefs.getUChar(key.c_str(), CONN_WIFI);
    }
    prefs.end();
    return type == CONN_UART || type == CONN_USB_CDC;
#else
    return false;
#endif
}

void setup()
{
    if (lastMachineUsesUart0()) {
        // Leave the debug console off: Serial.print() does nothing until
        // Serial.begin(), and FluidNCClient::connect() opens UART0 for FluidNC
        g_serialMuted = true;
        stopUart0Logging();
    } else {
        // Enlarge RX buffer before begin so a controller already pumping status
        // reports into UART0 can't overflow the default 256 B buffer during boot.
        Serial.setRxBufferSize(2048);
        Serial.begin(115200);
    }
    delay(1000);
    Serial.println("\n\n=== FluidTouch - LVGL 9 with LovyanGFX ===");
    Serial.printf("Free heap: %d bytes\n", ESP.getFreeHeap());
    Serial.printf("PSRAM size: %d bytes\n", ESP.getPsramSize());
    Serial.printf("Free PSRAM: %d bytes\n", ESP.getFreePsram());

    // Initialize Display Driver
    Serial.println("Initializing display driver...");
    static DisplayDriver displayDriver;
    if (!displayDriver.init()) {
        Serial.println("ERROR: Failed to initialize display!");
        while (1) delay(1000);
    }
    Serial.println("Display driver initialized successfully");
    
    // Load and apply display rotation preference
    {
        Preferences prefs;
        prefs.begin(PREFS_SYSTEM_NAMESPACE, true);  // Read-only
        uint8_t display_rotation = prefs.getUChar("display_rot", 0);  // Default to 0 (normal)
        prefs.end();
        
        Serial.printf("Main: Loading display rotation: %d degrees\n", display_rotation * 90);
        displayDriver.setRotation(display_rotation);
    }

    // Initialize Touch Driver
    Serial.println("Initializing touch driver...");
    static TouchDriver touchDriver;
    if (!touchDriver.init(displayDriver.getLCD())) {
        Serial.println("ERROR: Failed to initialize touch!");
        while (1) delay(1000);
    }
    Serial.println("Touch driver initialized successfully");

    // Initialize Power Manager
    Serial.println("Initializing power manager...");
    PowerManager::init(&displayDriver);
    Serial.println("Power manager initialized successfully");

    // Store display driver reference for later use (screenshot server after WiFi connects)
    UICommon::setDisplayDriver(&displayDriver);

    // Initialize Screenshot Server (WiFi not connected yet, will initialize after machine selection)
    Serial.println("Screenshot server will initialize after WiFi connection...");

    // Initialize FluidNC Client
    Serial.println("Initializing FluidNC client...");
    FluidNCClient::init();

    // Check for auto-import (only if no machines configured)
    Serial.println("Checking for settings auto-import...");
    if (SettingsManager::autoImportOnBoot()) {
        Serial.println("Settings imported successfully! Restarting...");
        delay(2000);  // Give user time to see serial message
        ESP.restart();
    }

    // Show splash screen
    Serial.println("Showing splash screen...");
    UISplash::show(displayDriver.getDisplay());

    // Check if machine selection should be shown
    Preferences prefs;
    prefs.begin(PREFS_SYSTEM_NAMESPACE, true);  // Read-only
    bool show_machine_select = prefs.getBool("show_mach_sel", true);  // Default to true
    prefs.end();
    
    Serial.printf("Main: show_mach_sel preference = %d\n", show_machine_select);
    
    if (show_machine_select) {
        // Show machine selection screen
        Serial.println("Showing machine selection screen...");
        UIMachineSelect::show(displayDriver.getDisplay());
    } else {
        // Auto-load the last machine used, or the first configured one
        Serial.println("Auto-loading last machine...");
        MachineConfig machines[MAX_MACHINES];
        MachineConfigManager::loadMachines(machines);

        int first_machine_index = MachineConfigManager::getSelectedMachineIndex();
        if (first_machine_index < 0 || first_machine_index >= MAX_MACHINES ||
            !machines[first_machine_index].is_configured) {
            first_machine_index = -1;
            for (int i = 0; i < MAX_MACHINES; i++) {
                if (machines[i].is_configured) {
                    first_machine_index = i;
                    break;
                }
            }
        }

        if (first_machine_index >= 0) {
            // Set as selected machine and initialize UI
            MachineConfigManager::setSelectedMachineIndex(first_machine_index);
            Serial.printf("Auto-selected machine: %s\n", machines[first_machine_index].name);
            
            // Initialize main UI directly
            UICommon::createMainUI();
        } else {
            // No machines configured, show selection screen anyway
            Serial.println("No machines configured, showing selection screen...");
            UIMachineSelect::show(displayDriver.getDisplay());
        }
    }
}

void loop()
{
    // Forward any Serial input to FluidNC (for debugging via Serial Monitor)
    // Skip in serial modes: the FluidNC link (UART0 header or USB CDC) is UART0,
    // the same UART as `Serial`.
    if (!FluidNCClient::isSerialMode()) {
        static char serial_buf[128];
        static uint8_t serial_buf_pos = 0;
        while (Serial.available()) {
            char c = Serial.read();
            if (c == '\n' || c == '\r') {
                if (serial_buf_pos > 0) {
                    serial_buf[serial_buf_pos++] = '\n';
                    serial_buf[serial_buf_pos] = '\0';
                    Serial.printf("[Serial->FluidNC] %s", serial_buf);
                    FluidNCClient::sendCommand(serial_buf);
                    serial_buf_pos = 0;
                }
            } else if (serial_buf_pos < sizeof(serial_buf) - 2) {
                serial_buf[serial_buf_pos++] = c;
            }
        }
    }

    // Handle screenshot server web requests
    ScreenshotServer::handleClient();
    
    // Handle FluidNC client WebSocket events
    FluidNCClient::loop();
    
    // Check for connection timeout (non-blocking)
    UICommon::checkConnectionTimeout();
    
    // Check for pending file list refresh (from Files tab delete callback)
    UITabFiles::checkPendingRefresh();
    
    // Poll XModem transfer state and update progress dialog (wired mode)
    UITabFiles::checkXModemProgress();
    
    // Update UI from FluidNC status (every 250ms)
    static uint32_t lastUIUpdate = 0;
    uint32_t currentMillis = millis();
    if (currentMillis - lastUIUpdate >= 250) {
        lastUIUpdate = currentMillis;
        
        bool machine_connected = FluidNCClient::isConnected();
        // In ESP-NOW mode the radio symbol shows the ESP-NOW link instead of WiFi
        bool wifi_connected = FluidNCClient::isEspNowMode() ? FluidNCClient::espnowLink().connected()
                                                            : (WiFi.status() == WL_CONNECTED);
        
        // Update connection status symbols (always update, even if not connected)
        UICommon::updateConnectionStatus(machine_connected, wifi_connected);
        
        // Update About tab screenshot server URL (in case WiFi status changed)
        UITabSettingsAbout::update();
        
        // Only update other status info if machine is connected
        if (machine_connected) {
            const FluidNCStatus& status = FluidNCClient::getStatus();
        
            // Update status bar
            const char* state_str = "IDLE";
            switch (status.state) {
                case STATE_IDLE: state_str = "IDLE"; break;
                case STATE_RUN: state_str = "RUN"; break;
                case STATE_HOLD: state_str = "HOLD"; break;
                case STATE_JOG: state_str = "JOG"; break;
                case STATE_ALARM: state_str = "ALARM"; break;
                case STATE_DOOR: state_str = "DOOR"; break;
                case STATE_CHECK: state_str = "CHECK"; break;
                case STATE_HOME: state_str = "HOME"; break;
                case STATE_SLEEP: state_str = "SLEEP"; break;
                default: state_str = "DISCONNECTED"; break;
            }
            
            UICommon::updateMachineState(state_str);
            UICommon::updateMachinePosition(status.mpos_x, status.mpos_y, status.mpos_z);
            UICommon::updateWorkPosition(status.wpos_x, status.wpos_y, status.wpos_z, status.wpos_a);

            // Check for HOLD/ALARM state and show popups if needed
            UICommon::checkStatePopups(status.state, status.last_message, status.alarm_message);

            // Update Control Actions pause/resume button based on machine state
            UITabControlActions::updatePauseButton(status.state);

            // Update Status tab
            UITabStatus::updateState(state_str);
            UITabStatus::updateWorkPosition(status.wpos_x, status.wpos_y, status.wpos_z, status.wpos_a);
            UITabStatus::updateMachinePosition(status.mpos_x, status.mpos_y, status.mpos_z, status.mpos_a);
            UITabStatus::updateFeedRate(status.feed_rate, status.feed_override);
            UITabStatus::updateRapidOverride(status.rapid_override);
            UITabStatus::updateSpindle(status.spindle_speed, status.spindle_override);
            UITabStatus::updateModalStates(status.modal_wcs, status.modal_plane, status.modal_distance,
                                        status.modal_units, status.modal_motion, status.modal_feedrate,
                                        status.modal_spindle, status.modal_coolant, status.modal_tool);
            UITabStatus::updateMessage(status.last_message);
            UITabStatus::updateLimitSwitches(status.pin_limit_x, status.pin_limit_y, status.pin_limit_z, status.pin_limit_a);
            UITabControlActions::updateLimitSwitches(status.pin_limit_x, status.pin_limit_y, status.pin_limit_z, status.pin_limit_a);
            UITabStatus::updateProbe(status.pin_probe);
            UITabControlProbe::updateProbe(status.pin_probe);
            
            // Update Main tab (reduced-axis machines) - no-ops if not created
            UITabMain::updateState(state_str);
            UITabMain::updateWorkPosition(status.wpos_x, status.wpos_y, status.wpos_z, status.wpos_a);
            UITabMain::updateMachinePosition(status.mpos_x, status.mpos_y, status.mpos_z, status.mpos_a);
            UITabMain::updateMessage(status.last_message);
            UITabMain::updateLimitSwitches(status.pin_limit_x, status.pin_limit_y, status.pin_limit_z, status.pin_limit_a);

            // Update file progress in status bar (UICommon) instead of status tab
            UICommon::updateFileProgress(status.is_sd_printing, status.sd_percent,
                                        status.sd_filename, status.sd_elapsed_ms);
            
            // Update control buttons visibility based on machine state
            UITabStatus::updateControlButtons(status.state);
            
            // Update Macros tab progress (only when a macro from that tab is running)
            static bool macro_print_started = false;  // Track if SD print actually started
            static unsigned long completion_display_start = 0;  // Track 100% display time
            static unsigned long macro_start_time = 0;  // Track when macro button was clicked
            static const unsigned long COMPLETION_DISPLAY_MS = 2000;  // Show 100% for 2 seconds
            static const unsigned long FAST_MACRO_TIMEOUT_MS = 1000;  // If no SD activity within 1s, assume macro completed
            bool is_macro_running = UITabMacros::isMacroRunning();
            
            // Detect when a new macro starts (transition from not running to running)
            static bool was_macro_running = false;
            if (is_macro_running && !was_macro_running) {
                // New macro just started
                macro_start_time = millis();
                macro_print_started = false;
                LOG_PRINTF("[Main] New macro started, tracking start time\n");
            }
            was_macro_running = is_macro_running;
            
            if (status.is_sd_printing && status.sd_percent > 0 && is_macro_running) {
                macro_print_started = true;  // Mark that print has started
                completion_display_start = 0;  // Reset completion timer while printing
                LOG_PRINTF("[Main] Showing progress: printing=%d, percent=%.1f, macro_running=%d\n", 
                    status.is_sd_printing, status.sd_percent, is_macro_running);
                // Use the stored macro name (not the SD filename)
                UITabMacros::updateProgress((int)status.sd_percent, UITabMacros::getRunningMacroName(), status.last_message);
                UITabMacros::showProgress();
            } else {
                // Check if macro completed (either we saw SD activity that stopped, or it was too fast)
                bool macro_completed = false;
                
                if (is_macro_running && macro_print_started && !status.is_sd_printing) {
                    // Normal case: SD print started and then stopped
                    macro_completed = true;
                    LOG_PRINTF("[Main] Macro completed (normal)\n");
                } else if (is_macro_running && !macro_print_started && macro_start_time > 0 && 
                          (millis() - macro_start_time >= FAST_MACRO_TIMEOUT_MS)) {
                    // Fast macro case: never saw SD activity, but enough time passed
                    macro_completed = true;
                    LOG_PRINTF("[Main] Macro completed (fast, no SD activity detected)\n");
                }
                
                if (macro_completed) {
                    // Macro completed - start 2-second display timer if not already started
                    if (completion_display_start == 0) {
                        completion_display_start = millis();
                        LOG_PRINTF("[Main] Showing 100%% for 2 seconds\n");
                        // Show 100% with the macro name
                        UITabMacros::updateProgress(100, UITabMacros::getRunningMacroName(), "Complete");
                        UITabMacros::showProgress();
                    } else {
                        // Check if 2 seconds have elapsed
                        if (millis() - completion_display_start >= COMPLETION_DISPLAY_MS) {
                            LOG_PRINTF("[Main] Completion display timeout, clearing macro\n");
                            UITabMacros::clearRunningMacro();
                            macro_print_started = false;
                            completion_display_start = 0;
                            macro_start_time = 0;
                            UITabMacros::hideProgress();
                        } else {
                            // Still within 2-second window, keep showing 100%
                            UITabMacros::showProgress();
                        }
                    }
                } else if (is_macro_running && !macro_print_started && macro_start_time > 0) {
                    // Macro is running but hasn't started SD print yet - keep showing progress
                    UITabMacros::showProgress();
                } else {
                    // No macro running, hide progress
                    UITabMacros::hideProgress();
                }
            }
            
            // Update Override tab
            UITabControlOverride::updateValues(status.feed_override, status.rapid_override, status.spindle_override);
            
            // Update power manager with current machine state. A G4 dwell
            // reports Idle mid-job; keep the display awake until the job ends.
            PowerManager::update(status.is_sd_printing ? STATE_RUN : status.state);
        } else {
            // Machine disconnected - show OFFLINE state and reset all values to dashes
            UICommon::updateMachineState("OFFLINE");
            UICommon::updateMachinePosition(-9999.0f, -9999.0f, -9999.0f);  // Triggers dash display
            UICommon::updateWorkPosition(-9999.0f, -9999.0f, -9999.0f, -9999.0f);     // Triggers dash display

            // Update Status tab with OFFLINE state and reset all values
            UITabStatus::updateState("OFFLINE");
            UITabStatus::updateWorkPosition(-9999.0f, -9999.0f, -9999.0f, -9999.0f);
            UITabStatus::updateMachinePosition(-9999.0f, -9999.0f, -9999.0f, -9999.0f);
            UITabStatus::updateFeedRate(-9999.0f, -9999.0f);  // Reset feed rate and override
            UITabStatus::updateRapidOverride(-9999.0f);        // Reset rapid override
            UITabStatus::updateSpindle(-9999.0f, -9999.0f);    // Reset spindle and override
            UITabStatus::updateModalStates("---", "---", "---", "---", "---", "---", "---", "---", "---");

            // Update Main tab with OFFLINE state and reset all values (no-ops if not created)
            UITabMain::updateState("OFFLINE");
            UITabMain::updateWorkPosition(-9999.0f, -9999.0f, -9999.0f, -9999.0f);
            UITabMain::updateMachinePosition(-9999.0f, -9999.0f, -9999.0f, -9999.0f);
            
            // Update power manager with OFFLINE state (treat as IDLE for power management)
            PowerManager::update(STATE_IDLE);
        }
    }
    
    // Check machine connection timeout
    UICommon::checkConnectionTimeout();
    
    // Update Terminal tab (batched UI updates every 100ms)
    UITabTerminal::update();
    
    // Update LVGL tick (CRITICAL for timers and input device polling!)
    static uint32_t lastTick = 0;
    lv_tick_inc(currentMillis - lastTick);
    lastTick = currentMillis;
    
    lv_timer_handler();
    delay(5);
    
    // Status update every 5 seconds
    static unsigned long lastUpdate = 0;
    if (millis() - lastUpdate > 5000) {
        lastUpdate = millis();
        LOG_PRINTF("[%lu] LVGL running, Free heap: %d, FluidNC: %s\n", 
                      millis()/1000, ESP.getFreeHeap(),
                      FluidNCClient::isConnected() ? "Connected" : "Disconnected");
    }
}

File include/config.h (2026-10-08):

#ifndef CONFIG_H
#define CONFIG_H

#include <Arduino.h>

// Version
#define FLUIDTOUCH_VERSION "1.1.0"

// Display settings
#define SCREEN_WIDTH  800
#define SCREEN_HEIGHT 480

// Hardware-specific pin configurations
#ifdef HARDWARE_ADVANCE
// CrowPanel 7" Advance - per Elecrow example code
// https://www.elecrow.com/pub/wiki/ESP32_Display-7.0_inch%28Advance_Series%29wiki.html
#define TOUCH_SDA  15
#define TOUCH_SCL  16
#define TOUCH_RST  -1  // Reset handled by STC8H1K28 microcontroller via I2C
#define TOUCH_INT  -1  // Not used
#else
// CrowPanel 7" Basic
#define TOUCH_SDA  19
#define TOUCH_SCL  20
#define TOUCH_RST  38
#define TOUCH_INT  -1
#endif

// Touch controller I2C address
#define GT911_ADDR 0x5D

// GT911 register addresses
#define GT911_POINT_INFO  0x814E
#define GT911_POINT_1     0x814F
#define GT911_CONFIG_REG  0x8047
#define GT911_PRODUCT_ID  0x8140

// UI Layout constants
#define STATUS_BAR_HEIGHT 60
#define TAB_BUTTON_HEIGHT 60

// Display buffer configuration
#define BUFFER_LINES 480  // Full screen buffer for smooth rendering (with 8MB PSRAM available)

// Timing constants
#define SPLASH_DURATION_MS 2500
#define LIMIT_SWITCH_HOLD_MS 500  // Duration to keep limit switch indicators visible after trigger clears

// Preferences namespaces
#define PREFS_NAMESPACE "fluidtouch"        // Machine configurations
#define PREFS_SYSTEM_NAMESPACE "ft_system"  // System flags (clean_shutdown, etc.)

// Screenshot server configuration
#define ENABLE_SCREENSHOT_SERVER true

// SD Card Configuration
#ifdef HARDWARE_ADVANCE
// Advance: SPI mode SD card
#define SD_MOSI  6
#define SD_MISO  4
#define SD_CLK   5
#define SD_CS    0  // Not actually connected - CS tied to GND in hardware (per Elecrow example)
#else
// Basic: SPI mode SD card
#define SD_MOSI  11
#define SD_MISO  13
#define SD_CLK   12
#define SD_CS    10
#endif

// Upload Configuration
#define FLUIDNC_UPLOAD_PATH "/fluidtouch/uploads/"  // Automatically created if missing

#endif // CONFIG_H

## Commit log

2026-02-08 Fix probe after WCS confirmation
    [ui_tab_control_probe.cpp]
2026-04-11 Update to LVGL 9.5.0, LovyanGFM 1.2.19, and ArduinoJson 7.4.3
2026-04-11 Status Tab Axis and Probe Indicators
2026-04-11 Update ESP32 Platform Branch
2026-04-21 Wired Connection Work in Progress
2026-04-22 Added Wired Upload via XModem
2026-04-23 Switch from UART0 (44/43) to UART1(19/20)
2026-04-23 Pin Specific Platform Commit
2026-04-24 Added Probe/Limit Switch Indicators on appropriate Control tabs and display limit for 500ms.
2026-05-05 READme.md Display info
    Add printed case link and move recommend display to first on the list.
2026-07-02 Wired Work in Progress
2026-07-03 Fixes #55 - mDNS Issue with File Upload from @Jfhow
    [fluidnc_client.cpp]
2026-07-03 Fixes #56 - Wrong Alarm Message Displayed and provides alarm message
    [fluidnc_client.cpp, main.cpp]
2026-09-24 WIP: Reduced-axis machine support
    Per-machine X/Y/Z enable switches (alongside existing A), Settings >
    General axis configuration section, status bar and Control tabs hide
    disabled axes, and a consolidated Main tab replaces Status when Y and Z
    are both disabled (e.g. CNC miter saw fence).
    Not yet built or tested on hardware. Known gaps: Status tab ignores
    disabled axes, settings import/export doesn't include X/Y/Z switches,
    no CHANGELOG entry.
    [machine_config.cpp, main.cpp, ui_tab_control_actions.cpp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]
2026-09-25 Handle FluidNC messages line by line
    FluidNC v4 (websocket port 80) sends controller output as newline-terminated
    lines in binary frames, sometimes several lines per frame and sometimes one
    long line split across frames. The client dispatched on the first character
    of each frame, so a status report bundled after another line was never
    parsed - e.g. after M0 the HOLD popup didn't appear until a separate '?'.
    FluidNCClient now reassembles binary frames into complete lines and passes
    each line to the parsers and callbacks individually (text frames such as
    PING/CURRENT_ID are passed through as-is). A partial line without a newline
    is flushed after 100 ms as a fallback.
    The Files tab also recog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
    [fluidnc_client.cpp]
2026-09-25 Add desktop simulator
    sim/ builds the firmware UI, main.cpp and FluidNC client unchanged as a
    desktop app (SDL2 window, mouse as touch) that connects to a real FluidNC
    controller over the PC's network. Desktop versions of the Arduino/ESP32
    APIs (Preferences, SD, WiFi, sockets, etc.) live in sim/include and sim/src.
    Includes a PowerShell build script (MSYS2 UCRT64 + SDL2), scripted input and
    screenshots (--script, F12), a PC-keyboard bridge for the on-screen keyboard,
    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
2026-09-25 Fix reduced-axis layout issues found in the simulator
    - Settings > General: axis switches in a 2x2 grid below the Display
    section so they no longer overlap its description or run off the
    right edge (affected every machine)
    - Main tab: zero tab padding and a layout that fits the 360px area, so
    the message and STOP button are no longer cut off
    - Joystick: only show the Z readout when the machine has a Z axis
    - Jog: "X Step"/"X Feed" (or Y) labels when only one of X/Y is enabled
    [ui_tab_control_jog.cpp, ui_tab_control_joystick.cpp, ui_tab_main.cpp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]
2026-09-25 Reduced-axis: Status tab rows and settings backup
    - Status tab hides the rows of disabled X/Y/Z axes and moves the rows
    below them up; the message box grows into the freed space (narrowed
    beside the feed/spindle column when it moves up)
    - Settings export/import now includes each machine's axis configuration
    (X/Y/Z/A); older backups without it import as X/Y/Z on, A off.
    Previously the A-axis switch wasn't exported either.
2026-09-25 Make Unlock buttons magenta instead of blue
    Blue is the X axis color, so Unlock gets its own theme color (BTN_UNLOCK).
    Used on Control > Actions and the reduced-axis Main tab.
2026-09-25 Rework reduced-axis Main tab for single-axis machines
    Organized for a miter saw stop / table saw fence workflow:
    - Left: state, X work position (tap to go to), jogging with the Jog
    settings' step sizes and feed, message box
    - Right: saved positions - Save records the current position (per
    machine, up to 8, sorted), tap to go there, long-press to delete; the
    one matching the current position gets a white border
    - Bottom: STOP / Home X / Zero X / Unlock as equal-size buttons
    Also: machine position is left to the status bar; state label shrinks its
    font to fit long states; tab notices ("Position already saved") are held
    for 3s so status updates don't overwrite them; fixed a NULL assert (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
    [ui_tab_main.cpp]
2026-09-25 Change Unlock button color to dark cyan
    Magenta didn't fit; dark cyan (#00838F) still stands apart from the X axis
    blue. Applies to Control > Actions and the Main tab via BTN_UNLOCK.
2026-09-25 Main tab: position row with jog buttons, captions like Status tab
    - Remove the state readout (always shown in the status bar) and the
    "tap to go to" hint
    - X- / X+ jog buttons now flank the work position field; narrower field
    - WORK POSITION and MESSAGE captions matching the Status tab
    - Limit indicator moved to the caption row as "LIMIT", styled like the
    Status tab's PRB indicator, and turns green (not red) like the Status tab
    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
2026-09-26 Simulator: stub FreeRTOS/Serial APIs used by the wired code
    The wired branch uses TaskHandle_t, vTaskDelay and
    Serial.setRxBufferSize() outside HARDWARE_ADVANCE guards; add desktop
    stubs so the simulator builds. Also bump the sim version to 1.1.0.
2026-09-26 Treat a running file job as busy even when FluidNC reports Idle
    FluidNC reports Idle during a G4 dwell inside a running SD/LocalFS
    file, so the Idle-only gates let actions through mid-job. Add
    FluidNCStatus::isIdle() (Idle and no SD: field) and use it for the
    Files list, the Go To position fields on the Status and Main tabs,
    and the power manager's dimming.
    Tested on a FluidNC 4.1.1 pen plotter with a file containing six G4
    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
2026-09-26 ESP-NOW link core with simulator radio and fake FluidNC side
    Client side of the FluidNC v4.0.4+ ESP-NOW pendant protocol, written from
    the protocol (FluidDial's client is GPL):
    - EspNowLink: P-256 pairing, session keepalives with anti-replay tags,
    fragmented line data, realtime bytes, channel search, and saved-pairing
    reconnect; presents the link as a byte stream
    - EspNowCrypto: mbedtls SHA-256/HMAC/ECDH wrappers
    - EspNowRadio: frame-level interface; the ESP32 implementation comes later
    Simulator:
    - UDP ESP-NOW radio that carries the channel and per-peer encryption state
    - fake_fluidnc.py plays FluidNC's side ($espnow/pair etc., pure-Python
    P-256) and rejects frames on the wrong chann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
2026-09-26 Connect to FluidNC over ESP-NOW
    ESP-NOW is now a working connection type (CONN_ESPNOW):
    - FluidNCClient runs the EspNowLink as a line stream: on link-up it
    enables auto-reporting and requests $Build/Info like a WebSocket
    connection; on link loss the machine shows as disconnected until the
    link finds FluidNC again. All sends go through one sendRaw() path.
    - The pairing is stored per machine slot (NVS blob m<n>_enow) and saved
    again when FluidNC turns up on another WiFi channel.
    - ESP-NOW machines skip WiFi, show "ESP-NOW" in the status bar and on the
    machine card, get 20 s (not 10 s) before the connection error, and an
    ESP-NOW-specific error message.
    - ESP32 ESP-NOW radio (esp_now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
    [fluidnc_client.cpp, machine_config.cpp, main.cpp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]
2026-09-26 Simulator: build as the CrowPanel Advance
    The Advance is the main board, so the simulator now defines
    HARDWARE_ADVANCE and offers the UART, USB CDC and ESP-NOW connection
    types. Stubs for the Advance-only code paths:
    - HardwareSerial ports other than the console are silent (nothing is
    connected to the simulated UART)
    - FreeRTOS task creation runs the task as a detached thread
2026-09-26 Pair ESP-NOW machines from the machine editor
    - ESP-NOW is a connection type in the machine editor (Advance and
    Basic). Choosing it replaces the network fields with an ESP-NOW
    pairing panel: status, instructions and a Pair / Cancel button. The
    pairing is kept once the machine is saved.
    - Machine cards show FluidNC's hostname, or "Not paired", for ESP-NOW
    machines.
    - The Files tab leaves out Upload buttons in ESP-NOW mode (FluidNC can't
    receive XModem on its ESP-NOW channel, and there's no WiFi for HTTP).
    Tested in the simulator against the fake FluidNC: re-paired a machine
    through the editor on a new channel, saved, and connected with the new
    pairing.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
    [ui_machine_select.cpp]
2026-09-26 ESP-NOW: hardware diagnostics, re-add peers instead of modifying
    First hardware test: pairing with FluidNC 4.1.1 works, but every
    encrypted esp_now_add_peer fails. The Jason2866 platform's prebuilt
    libraries set CONFIG_ESP_WIFI_ESPNOW_MAX_ENCRYPT_NUM to 0, so no
    encrypted peers are possible, and FluidNC requires encryption once
    paired. Diagnostics added to find this:
    - log peer add results, send failures and set-channel failures
    - count frames FluidNC's radio acknowledged / didn't (send callback)
    - log each search probe, frames from FluidNC while not connected,
    rejected keepalives, and repeated pairing results
    setPeer() now deletes and re-adds a peer rather than using
    esp_now_mod_peer, so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
2026-09-26 Move to the official pioarduino platform (Arduino 3.3.12, ESP-IDF 5.5.5)
    Replaces the Jason2866 platform (Arduino on ESP-IDF 5.3) with pioarduino
    55.03.312-1, which packages Espressif's official Arduino core and
    libraries. Needs PlatformIO Core 6.2.0 or later.
    - custom_sdkconfig enables CONFIG_SPIRAM_XIP_FROM_PSRAM. The official
    libraries leave it off, and without it the RGB panel flickers
    constantly: flash and PSRAM share the memory bus, and flash fetches
    starve the display DMA. The Jason libraries had it on. Setting it makes
    the platform rebuild the framework libraries once (slow first build).
    - Removes the -DCONFIG_SPIRAM_* / -DCONFIG_ESP32S3_DATA_CACHE_LINE_32B
    build flags. Wi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
2026-09-26 ESP-NOW: trim the diagnostic logging
    The connection works on hardware (FluidNC 4.1.1 pen plotter), so the
    diagnostics from the first hardware test are cut back:
    - peers are logged only when adding one fails
    - no per-second "Searching channel" line or per-frame logging; one line
    when the saved channel gets no answer and the full sweep starts, with
    the radio's acknowledged / not-acknowledged counts (logged then, so
    they are meaningful)
    - kept: send and set-channel failures, rejected keepalives (capped), and
    FluidNC resending its pairing result
2026-09-26 Wired: use the UART0 header, keep debug output out of FluidNC
    Tested with an Eggbot on FluidNC 4.1.1 over the Advance's UART0 header:
    connects on warm and cold power-up, auto-reporting (green icon), no
    stray commands reaching FluidNC.
    - UART mode uses UART0 (TX=GPIO43, RX=GPIO44), the header that can also
    power the display, instead of UART1 (GPIO19/20). It shares the USB CDC
    code path, since both are UART0 (USB CDC goes through the CH340).
    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
2026-09-26 Machine editor: per-type fields and "Load this machine at startup"
    - With the machine select screen turned off, FluidTouch now loads the
    last machine used instead of the first configured slot (falling back
    to the first if the last one is gone). Reordering machines keeps that
    pointing at the same machine. The Settings > General description and
    docs/ui-guide.md say so.
    - The machine editor has a "Load this machine at startup (skips the
    machine list)" switch for every connection type. On: saving makes this
    the startup machine and turns off the machine select screen. Off for
    the startup machine: turns the machine select screen back on. It
    reflects the current setting when editing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
    [main.cpp, ui_machine_select.cpp, ui_tab_settings_general.cpp]
2026-09-26 Correct the baud rate comment: USB CDC uses it too
    FluidNC's USB host sets the Advance's CH340 bridge to its
    `usb_host: baud:`, so FluidTouch's USB CDC baud has to match it, even
    though FluidNC's wiki says the baud doesn't matter (true only for
    natively USB devices).
2026-09-26 ESP-NOW: require FluidNC v4.1.0 in user-facing messages
    The ESP-NOW protocol first appeared in FluidNC v4.0.4, but that release
    had issues, so the pairing panel hints and the connection error now name
    v4.1.0 as the minimum.
    [ui_machine_select.cpp]
2026-09-26 Machine select: show the baud rate on UART and USB CDC cards
    The third line of a machine card was always URL:port, so wired machines
    showed whatever was left in their WiFi fields. UART and USB CDC cards
    now show their baud rate (WiFi keeps URL:port, ESP-NOW its paired
    hostname).
2026-09-27 PlatformIO: keep packages, platforms and cache in the project
    FluidTouch and FluidNC use different pioarduino platform versions, and
    building both from the shared ~/.platformio made each replace the
    other's framework and toolchain packages. Put packages_dir,
    platforms_dir and cache_dir under .pio/ (already git-ignored) so this
    project's builds are self-contained.
2026-09-27 Workflows: take boot_app0.bin from the project's .pio/packages
    platformio.ini now keeps packages under .pio/packages, so boot_app0.bin
    is no longer in ~/.platformio. Both workflows only copied it `if [ -f ]`,
    so previews and releases would have been published without it, and the
    web installer flashes it at 0xE000. Use the new location (falling back
    to the old one) and fail the build if it's missing. The preview workflow
    also saves it before it deletes .pio to switch to gh-pages.
2026-10-08 Hardware: add 3D printed case and stand for the CrowPanel Advance 7"
    FreeCAD source models with print-oriented .3mf/.stl exports and READMEs
    covering print settings, hardware, assembly and mounting. FreeCAD files
    are saved uncompressed so git can delta them; .FCBak backups and the
    local .mcp.json are ignored.
    [CrowPanelAdvance7Case-BatteryBracket.3mf, CrowPanelAdvance7Case-BatteryBracket.stl, CrowPanelAdvance7Case-Bottom.3mf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]
2026-10-08 Case: add the second battery bracket to the assembly
    Seat the bracket on its posts (it sat 0.4 mm into them) and add a linked
    copy on the second pair of posts. The bracket's shape and print file are
    unchanged.
    [CrowPanelAdvance7Case.FCStd]
2026-10-08 Docs: link the 3D printed case and list Advance v1.4/v1.5 support
    Replace the forum link with the in-repo case and stand, and note that
    v1.3-v1.5 boards share firmware. Remove the pendant adapter reference
    from the case model; the case supports wireless and USB, not UART.
    [CrowPanelAdvance7Case.FCStd]

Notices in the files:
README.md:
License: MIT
